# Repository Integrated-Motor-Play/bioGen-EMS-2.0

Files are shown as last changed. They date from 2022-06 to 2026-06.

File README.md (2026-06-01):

# bioGen-EMS-2.0

**bioGen-EMS 2.0** is an open-source, programmable four-channel Electrical Muscle Stimulation (EMS) toolkit for HCI research, rehabilitation experiments, interactive installations, and body-actuating games.

It builds on [bioGen-EMS](https://github.com/Integrated-Motor-Play/bioGen-EMS) and works with [Auto-Paizo](https://github.com/Integrated-Motor-Play/Auto-Paizo) using a shared single-character control protocol over USB serial and BLE.

## Table of contents

- [Features](#features)
- [Circuit](#circuit)
- [Repository layout](#repository-layout)
- [Quick start](#quick-start)
- [Documentation](#documentation)
- [Hardware requirements](#hardware-requirements)
- [Safety](#safety)
- [Contributing](#contributing)
- [License](#license)

## Features

- **Four-channel relay control** via demultiplexer select lines (D1–D4)
- **Auto-Paizo compatible** commands (`A/a` … `D/d`, `E/e`, `r`) on serial and BLE
- **EMG telemetry** over BLE (Grove EMG on A0)
- **Production firmware** for Seeed XIAO nRF52840
- **Python CLI** for bench testing without Unity
- **Open-source** hardware CAD, circuit, and firmware (MIT)

## Circuit

bioGen-EMS-2.0 Circuit

Schematic: [`Circuit Designs/bioGen-EMS-2.0.ckt`](Circuit%20Designs/bioGen-EMS-2.0.ckt) (open in Cirkit Studio)

## Repository layout

```
bioGen-EMS-2.0/
├── firmware/biogen_ems/    # Production sketch (Seeed XIAO nRF52840)
├── python/                 # Serial control CLI
├── examples/               # Example scripts
├── docs/                   # BOM, assembly, safety, protocol, enclosure
├── hardware/               # Hardware documentation index
├── CAD Files/              # Enclosure V2.0–V2.2 (use V2.2)
├── Circuit Designs/
└── Test Code/              # Legacy bring-up sketches (deprecated)
```

## Quick start

### 1. Clone and install Python dependencies

```bash
git clone https://github.com/Integrated-Motor-Play/bioGen-EMS-2.0.git
cd bioGen-EMS-2.0
pip install -r python/requirements.txt
```

### 2. Flash firmware

1. Install the [Seeed nRF52 board package](https://wiki.seeedstudio.com/XIAO_BLE/) in Arduino IDE.
2. Install the **ArduinoBLE** library from Library Manager.
3. Open [`firmware/biogen_ems/biogen_ems.ino`](firmware/biogen_ems/biogen_ems.ino).
4. Select **Seeed XIAO nRF52840** and upload.

See [firmware/README.md](firmware/README.md) for the smoke-test checklist.

### 3. Control over USB serial

```bash
# List available serial ports
python python/ems_control.py --list-ports

# Pulse channel 1 for 500 ms (auto-selects first port if --port omitted)
python python/ems_control.py --port /dev/cu.usbmodem101 --pulse 1 --duration 500

# Turn channel 2 on / off
python python/ems_control.py --port /dev/cu.usbmodem101 --channel 2 --on
python python/ems_control.py --port /dev/cu.usbmodem101 --channel 2 --off

# Reset all channels
python python/ems_control.py --port /dev/cu.usbmodem101 --reset
```

On Windows, use `COM3` (or your port) instead of `/dev/cu.usbmodem101`.

Example script: [`examples/basic_stim.py`](examples/basic_stim.py)

### 4. Build the hardware

1. [Bill of materials](docs/bom.md)
2. [Assembly guide](docs/assembly.md)
3. [Enclosure V2.2](docs/enclosure.md) — laser-cut acrylic + 3D-printed top/base

### 5. Use with Auto-Paizo

Pair over BLE and run calibration before participant sessions. See [docs/auto-paizo.md](docs/auto-paizo.md).

## Documentation

| Document | Description |
|---|---|
| [docs/bom.md](docs/bom.md) | Bill of materials |
| [docs/pinout.md](docs/pinout.md) | MCU pin mapping |
| [docs/protocol.md](docs/protocol.md) | Serial and BLE command reference |
| [docs/assembly.md](docs/assembly.md) | Build order and wiring |
| [docs/safety.md](docs/safety.md) | Safety and ethics guidelines |
| [docs/enclosure.md](docs/enclosure.md) | V2.2 enclosure manufacturing files |
| [docs/changelog-hardware.md](docs/changelog-hardware.md) | Enclosure revision history |
| [docs/auto-paizo.md](docs/auto-paizo.md) | Unity / Auto-Paizo integration |
| [hardware/README.md](hardware/README.md) | Hardware doc index |
| [CAD Files/README.md](CAD%20Files/README.md) | CAD file index |

## Hardware requirements

| Component | Notes |
|---|---|
| Seeed XIAO nRF52840 | Main controller |
| 4× Adafruit STEMMA Relay (4409) | Per-channel switching |
| 4-channel demux | Select lines on D1–D4 |
| Off-the-shelf EMS/TENS unit | Stimulation source (switched by relays) |
| Grove EMG Detector | Optional; muscle activity on A0 |
| Electrodes and cables | Per EMS unit manufacturer |

## Safety

EMS affects the human body. Read [docs/safety.md](docs/safety.md) before building or running studies. Use ethics approval, informed consent, conservative intensity, and never test on participants without proper calibration and supervision.

## Contributing

1. Fork the repository.
2. Create a branch: `git checkout -b feature/your-feature`
3. Commit your changes and open a pull request.

## License

MIT — see [LICENSE](LICENSE).

## Contact

hello@rakeshpatibanda.com

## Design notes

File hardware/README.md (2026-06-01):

# Hardware

Index for building the bioGen-EMS 2.0 device.

| Resource | Description |
|---|---|
| [docs/bom.md](../docs/bom.md) | Bill of materials |
| [docs/assembly.md](../docs/assembly.md) | Step-by-step assembly |
| [docs/pinout.md](../docs/pinout.md) | MCU pin mapping |
| [docs/enclosure.md](../docs/enclosure.md) | V2.2 enclosure files |
| [docs/safety.md](../docs/safety.md) | Safety guidelines |
| [Circuit Designs/bioGen-EMS-2.0.ckt](../Circuit%20Designs/bioGen-EMS-2.0.ckt) | Cirkit Studio schematic |
| [CAD Files/README.md](../CAD%20Files/README.md) | Enclosure file index |

Firmware: [firmware/README.md](../firmware/README.md)

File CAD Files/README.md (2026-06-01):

# CAD Files

## Current revision: V2.2

Use **`V2.2/`** for all new builds. See [docs/enclosure.md](../docs/enclosure.md).

### Files you need

| Process | Path |
|---|---|
| Laser cut (acrylic) | `V2.2/Acrylic.DXF`, `V2.2/Acrylic_front_back.DXF`, `V2.2/Acrylic_side.DXF`, `V2.2/Acrylic_right_left.DXF` |
| 3D print | `V2.2/Top.STL`, `V2.2/Base.STL` |

### Source CAD

SolidWorks assembly: `V2.2/BioGen_Box_Assembly.SLDASM`

## Legacy revisions

| Folder | Status |
|---|---|
| `V2.0/` | Legacy — early box + middle sections |
| `V2.1/` | Legacy — panelized drawings in `Drawings/` |
| `V2.2/` | **Current** |

Hardware changelog: [docs/changelog-hardware.md](../docs/changelog-hardware.md).

## Logo

`XGL_large X.png` — project branding asset.

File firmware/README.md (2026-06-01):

# Firmware

Production sketch: [`biogen_ems/biogen_ems.ino`](biogen_ems/biogen_ems.ino)

**Target board:** Seeed XIAO nRF52840 (Sense or non-Sense)

## Setup (Arduino IDE)

1. Install [Arduino IDE](https://www.arduino.cc/en/software) 2.x.
2. Add board package: **Seeed nRF52 Boards** via Board Manager (`https://files.seeedstudio.com/arduino/package_seeeduino_boards_index.json`).
3. Install library: **ArduinoBLE** (Library Manager).
4. Open `biogen_ems/biogen_ems.ino`.
5. Select **Seeed XIAO nRF52840** → upload.

## Configuration

Edit [`biogen_ems/config.h`](biogen_ems/config.h):

| Define | Default | Purpose |
|---|---|---|
| `PIN_SEL_A`–`D` | 1–4 | Demux select lines |
| `EMG_PIN` | A0 | Grove EMG analog input |
| `EMG_DEBUG_SERIAL` | 0 | Set `1` for CSV on Serial |
| `BLE_DEVICE_NAME` | BioGen-EMS | BLE advertised name |

## Smoke test checklist

Perform **without electrodes on a participant**.

### 1. Serial connection

1. Connect XIAO via USB; note the serial port (e.g. `/dev/cu.usbmodem*` on macOS).
2. Open Serial Monitor at **115200** baud.
3. Confirm boot message: `bioGen-EMS ready`.

### 2. Channel commands

Send one character per line (no intensity control):

| Send | Expected |
|---|---|
| `A` | Channel 1 ON (D1 HIGH, D2–D4 LOW) |
| `a` | Channel 1 OFF |
| `B` | Channel 2 ON |
| `r` | All channels OFF |

Verify with a multimeter or LED on demux lines if relays are not yet wired.

### 3. Python CLI

```bash
pip install -r python/requirements.txt
python python/ems_control.py --list-ports
python python/ems_control.py --port /dev/cu.usbmodemXXXX --pulse 1 --duration 500
python python/ems_control.py --port /dev/cu.usbmodemXXXX --reset
```

### 4. BLE (optional)

1. Scan for **BioGen-EMS** from a phone or nRF Connect.
2. Connect to service `19B10000-E8F2-537E-4F6C-D104768A1214`.
3. Write `0x42` (`B`) to characteristic `19B10001-...` → channel 2 ON.
4. Subscribe to EMG characteristic `19B10002-...` for int32 notifications.

### 5. Auto-Paizo

Flash this firmware, then follow [docs/auto-paizo.md](../docs/auto-paizo.md).

## Troubleshooting

| Issue | Check |
|---|---|
| BLE init failed | Board package and ArduinoBLE installed |
| No serial port | USB cable supports data; driver for J-Link/USB |
| Wrong channel | [docs/pinout.md](../docs/pinout.md) wiring vs `config.h` |
| EMG flatline | Grove EMG on A0; sensor powered |

## Legacy tests

Bring-up sketches in [`Test Code/`](../Test%20Code/) are deprecated; use this firmware instead.

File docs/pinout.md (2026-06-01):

# Pinout (Seeed XIAO nRF52840)

Production firmware: [`firmware/biogen_ems/`](../firmware/biogen_ems/).

## Demux select lines (channels 1–4)

| Signal | XIAO pin | Arduino define | Channel |
|---|---|---|---|
| SEL_A | D1 | `PIN_SEL_A` (1) | 1 |
| SEL_B | D2 | `PIN_SEL_B` (2) | 2 |
| SEL_C | D3 | `PIN_SEL_C` (3) | 3 |
| SEL_D | D4 | `PIN_SEL_D` (4) | 4 |

Each channel is selected by driving one select line HIGH and the others LOW. Reset (`r`) drives all select lines LOW.

Validated in [`Test Code/Test_Demux/Test_Demux.ino`](../Test%20Code/Test_Demux/Test_Demux.ino).

## EMG sensor

| Signal | Pin | Notes |
|---|-----|---|
| EMG analog | A0 | Production firmware (`EMG_PIN`) |
| EMG analog (legacy test) | A7 | Used in early `sketch_jul11a` demo only |

Connect the Grove EMG Detector to the analog input per Grove wiring (typically A0 on XIAO).

## Channel 0 (protocol `E` / `e`)

Auto-Paizo uses channel 0 for some game mappings. With a 4-line demux, channel 0 is implemented as **all select lines LOW** (no channel selected). `E` enables that idle state; `e` is equivalent to off.

## Built-in LED

`LED_BUILTIN` may toggle on channel activity for debugging (optional in firmware).

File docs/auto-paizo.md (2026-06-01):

# Auto-Paizo Integration

[bioGen-EMS 2.0](https://github.com/Integrated-Motor-Play/bioGen-EMS-2.0) is designed to work with [Auto-Paizo](https://github.com/Integrated-Motor-Play/Auto-Paizo), a Unity project for body-actuating play research.

## Requirements

- Seeed XIAO nRF52840 flashed with [`firmware/biogen_ems/biogen_ems.ino`](../firmware/biogen_ems/biogen_ems.ino)
- Windows or macOS with Bluetooth LE
- Auto-Paizo built from source (see Auto-Paizo README)

## Pairing

1. Power the controller; do **not** attach electrodes to a participant yet.
2. Put the XIAO in range; ensure firmware BLE is advertising (device name: `BioGen-EMS`).
3. Pair from the OS Bluetooth settings if required by your platform.
4. In Auto-Paizo, open the Bluetooth Connect scene and select the device via `BluetoothConnector`.

## Protocol

Auto-Paizo sends the same single-character commands documented in [protocol.md](protocol.md) to the BLE command characteristic.

EMG calibration uses the EMG characteristic notify stream (32-bit integer level).

## Calibration

Use in-app panels before participant play:

- `EMGCalibrationPanel`
- `EMGSensitivitySlider`

Hold the target muscle steady during baseline capture (see Grove EMG notes in firmware README).

## Safety

Follow [safety.md](safety.md) and your ethics protocol. Auto-Paizo documentation also lists conservative intensity and participant communication practices.

## Differences from bioGen-EMS 1.0

| | v1 | v2 |
|---|----|----|
| MCU | Adafruit Feather 32u4 Bluefruit LE | Seeed XIAO nRF52840 |
| Transport | Classic Bluetooth serial | BLE GATT + USB serial |
| Enclosure | Burger v1 STL | V2.2 box |
| Commands | Same `A/a`…`D/d`, `E/e`, `r` | Same |

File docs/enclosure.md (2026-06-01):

# Enclosure (V2.2 — current)

Use **`CAD Files/V2.2/`** for new builds. Older revisions (V2.0, V2.1) are legacy references only.

## V2.2 manufacturing files

### Laser cut (acrylic)

| File | Purpose |
|---|---|
| `Acrylic.DXF` | Main acrylic layout |
| `Acrylic_front_back.DXF` | Front/back panels |
| `Acrylic_side.DXF` | Side panels |
| `Acrylic_right_left.DXF` | Left/right panels |

### 3D print

| File | Purpose |
|---|---|
| `Top.STL` | Top shell |
| `Base.STL` | Bottom shell |

### SolidWorks source

Assembly and parts: `BioGen_Box_Assembly.SLDASM`, `Top.SLDPRT`, `Base.SLDPRT`, `Front-Back.SLDPRT`, `Left-Right.SLDPRT`, `Board.SLDPRT`, `Speaker.SLDPRT`.

### CNC / other

- `BioGen_Box_Assembly.gcode` — machine-specific; verify settings before running on your printer/CNC.

## Legacy revisions

| Version | Folder | Notes |
|---|---|---|
| V2.0 | `CAD Files/V2.0/` | Early burger-style stack; Seeed Xiao + STEMMA relay CAD |
| V2.1 | `CAD Files/V2.1/` | Panelized wood/acrylic drawings in `Drawings/` |
| V2.2 | `CAD Files/V2.2/` | **Current** — simplified acrylic, speaker cutout |

See [changelog-hardware.md](changelog-hardware.md) for differences.

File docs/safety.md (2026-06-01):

# Safety Guidelines

Electrical muscle stimulation (EMS) affects the human body. Use bioGen-EMS 2.0 only with appropriate training, ethics approval, and informed consent.

## Before every session

1. Obtain institutional ethics approval for human-participant research.
2. Explain the procedure and obtain informed consent.
3. Inspect electrodes and cables for damage.
4. Set the external EMS unit to the **lowest effective intensity**.
5. Run `r` (reset all channels) before attaching electrodes.
6. Calibrate using Auto-Paizo or serial EMG readout before gameplay.

## Electrode placement

- Follow manufacturer guidance for the EMS unit and electrodes.
- Do **not** place stimulation electrodes on the head, neck, chest, or broken skin.
- Avoid stimulation across the heart.
- Use only intended muscle groups for your study protocol.

## During use

- Participants must be able to stop stimulation immediately (researcher disconnects or sends `r`).
- Monitor for pain, burns, skin irritation, or unexpected muscle reactions.
- Keep sessions within approved duration and intensity limits.
- Never leave stimulation unattended.

## Contraindications (consult a qualified clinician)

Do not use EMS on participants with pacemakers, pregnancy, epilepsy, or other conditions where electrical stimulation is contraindicated unless explicitly cleared by medical oversight.

## Hardware

- Verify relay wiring before connecting the EMS unit.
- Use battery or isolated supplies as designed; avoid mains-connected DIY stim circuits.
- This kit **switches** an off-the-shelf EMS device; it does not replace certified medical device safety review.

## Research documentation

Record calibration values, channel mappings, and any adverse events per your ethics protocol.

Contact: hello@rakeshpatibanda.com for project questions.

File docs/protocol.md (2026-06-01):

# Control Protocol

bioGen-EMS 2.0 uses the same single-character command set as [Auto-Paizo](https://github.com/Integrated-Motor-Play/Auto-Paizo). Commands are one ASCII character; an optional trailing newline (`\n`) is accepted.

## Channel commands

| Command | Channel | Action |
|---|---|---|
| `A` | 1 | ON |
| `a` | 1 | OFF |
| `B` | 2 | ON |
| `b` | 2 | OFF |
| `C` | 3 | ON |
| `c` | 3 | OFF |
| `D` | 4 | ON |
| `d` | 4 | OFF |
| `E` | 0 | ON (all demux lines low / idle) |
| `e` | 0 | OFF |
| `r` | — | Reset all channels OFF |

There is **no intensity command** in this protocol. Stimulation strength is set on the external EMS unit; the controller only selects which channel is active.

## USB serial

- Baud rate: **115200**
- Send one character per command, e.g. `A` or `A\n`
- EMG debug CSV (when enabled): `raw,filtered,level` per line at 10 ms interval

## BLE GATT (Auto-Paizo compatible)

| Role | UUID |
|---|---|
| Service | `19B10000-E8F2-537E-4F6C-D104768A1214` |
| Command (write) | `19B10001-E8F2-537E-4F6C-D104768A1214` |
| EMG (notify) | `19B10002-E8F2-537E-4F6C-D104768A1214` |

- Write a single command byte to the command characteristic.
- EMG level is sent as a **32-bit signed integer** (little-endian) on notify.

## Example session (serial)

```text
A    # channel 1 ON
a    # channel 1 OFF
B    # channel 2 ON
r    # all OFF
```

## Python

See [`python/ems_control.py`](../python/ems_control.py) and [`python/biogen_protocol.py`](../python/biogen_protocol.py).

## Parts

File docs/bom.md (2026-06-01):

# Bill of Materials

Parts identified from the circuit design ([`Circuit Designs/bioGen-EMS-2.0.ckt`](../Circuit%20Designs/bioGen-EMS-2.0.ckt)) and CAD assembly (V2.2).

## Electronics

| Qty | Part | MPN / ID | Notes |
|-----|---|---|---|
| 1 | Seeed XIAO nRF52840 | — | Main MCU; USB serial + BLE |
| 1 | Seeed XIAO Expansion Board | — | Optional; matches V2.0 CAD |
| 4 | Adafruit STEMMA Relay | 4409 | Channel switching |
| 1 | SparkFun connector | PRT-13854 | Per circuit file |
| 1 | 4-channel demultiplexer | — | Select lines driven by D1–D4 |
| 1 | Grove EMG Detector | — | Muscle activity sensing on A0 |
| 1 | Off-the-shelf EMS/TENS unit | — | Stimulation source; switched by relays |
| — | Electrode pads & cables | — | For EMS output and EMG input |

## Enclosure (V2.2)

| Process | Files |
|---|---|
| Laser cut (acrylic) | `CAD Files/V2.2/Acrylic*.DXF` |
| 3D print | `CAD Files/V2.2/Top.STL`, `CAD Files/V2.2/Base.STL` |

See [enclosure.md](enclosure.md) for full file list.

## Tools

- Soldering iron, wire, breadboard or PCB
- Arduino IDE with Seeed nRF52 board package
- Laser cutter and/or 3D printer (for enclosure)

## Purchasing

- [Adafruit STEMMA Relay (4409)](https://www.adafruit.com/product/4409)
- [Seeed XIAO nRF52840](https://www.seeedstudio.com/XIAO-BLE-Sense-p-3721.html)
- [Grove EMG Detector](https://www.seeedstudio.com/Grove-EMG-Detector-p-1737.html)

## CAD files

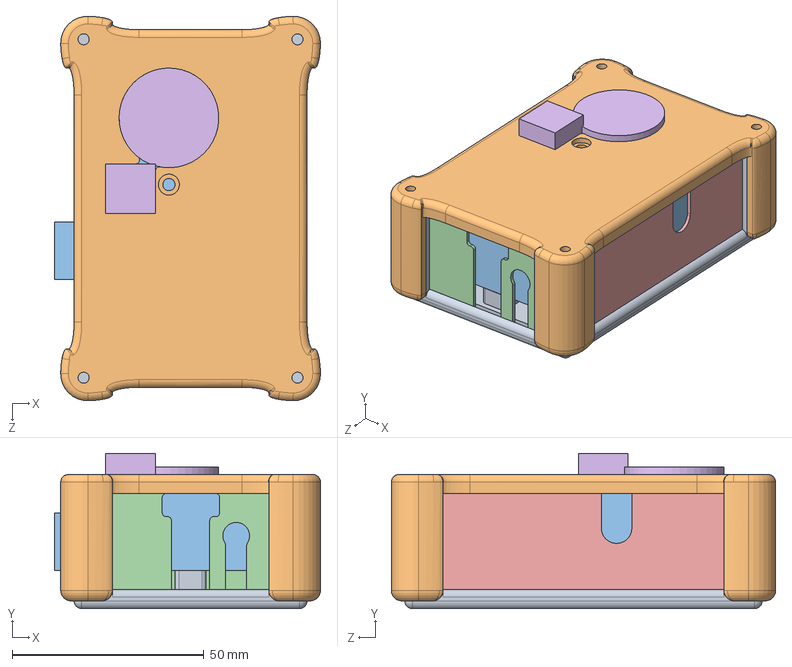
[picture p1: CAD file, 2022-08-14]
CAD Files/V2.2/BioGen_Box_Assembly.SLDASM
69.4 x 40.5 x 100.3 mm
Base
Top
Board
Front-Back x 2
Left-Right x 2

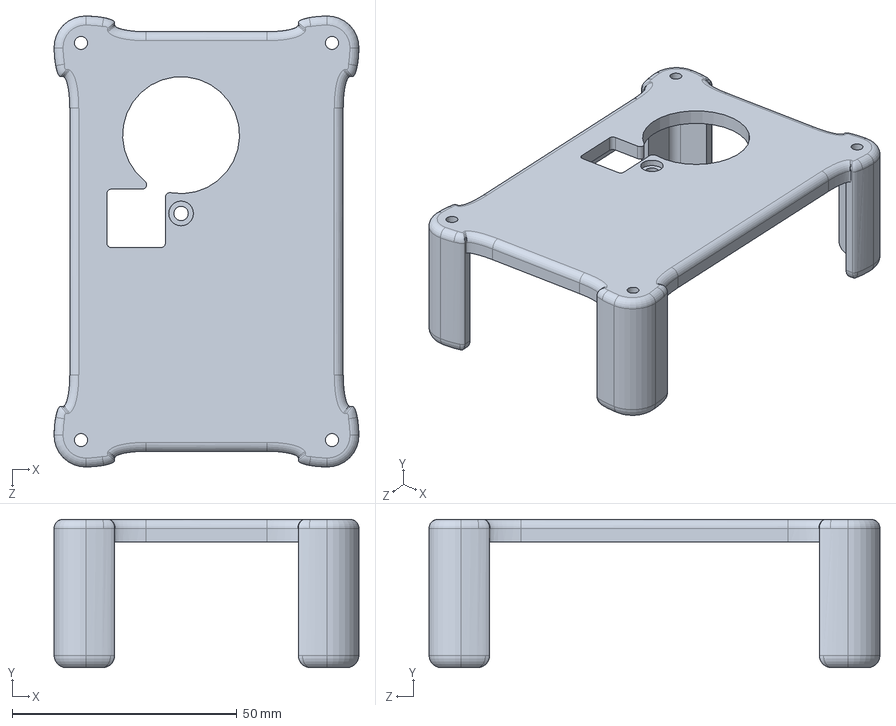
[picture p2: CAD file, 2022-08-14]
CAD Files/V2.2/Top.SLDPRT
67.8 x 33.0 x 100.3 mm

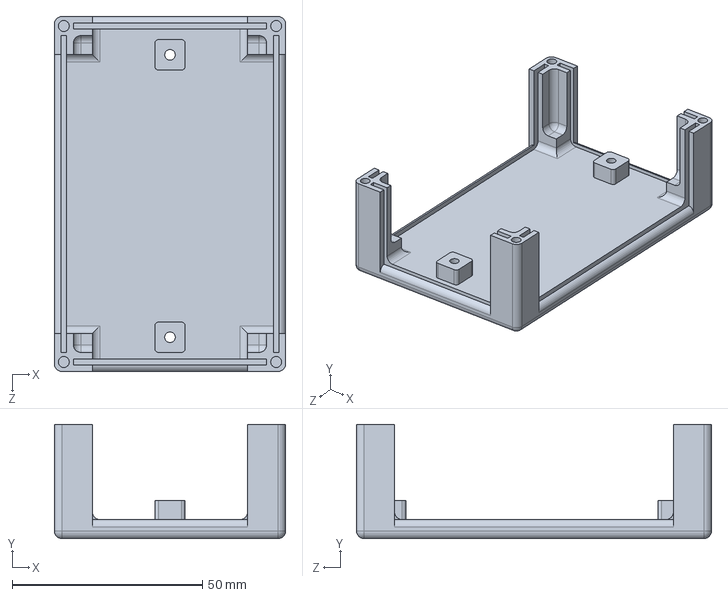
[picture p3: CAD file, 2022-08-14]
CAD Files/V2.2/Base.SLDPRT
60.8 x 30.0 x 93.3 mm

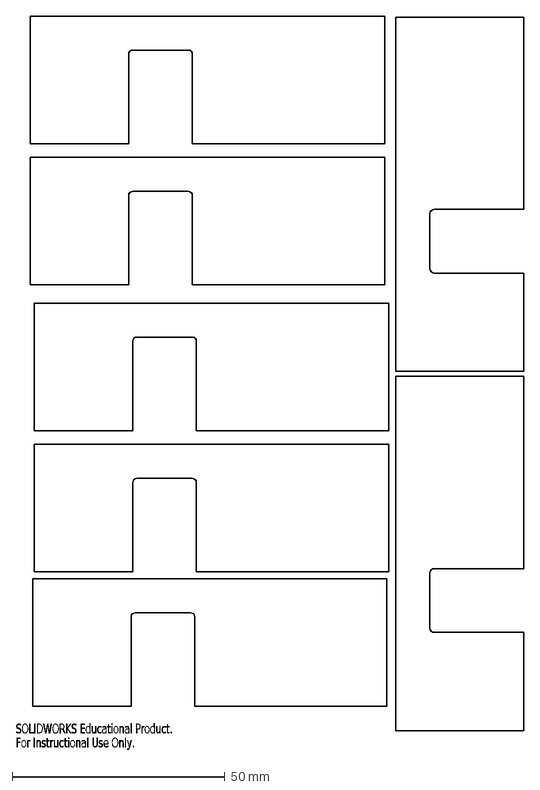
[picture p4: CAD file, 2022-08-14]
CAD Files/V2.2/Acrylic_side.DXF
SOLIDWORKS Educational Product.
For Instructional Use Only.

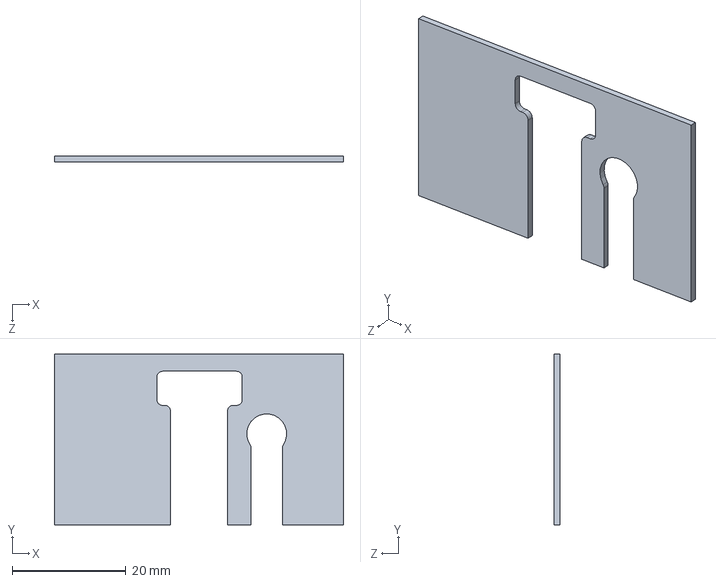
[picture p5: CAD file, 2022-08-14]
CAD Files/V2.2/Front-Back.SLDPRT
50.8 x 30.0 x 1.00 mm

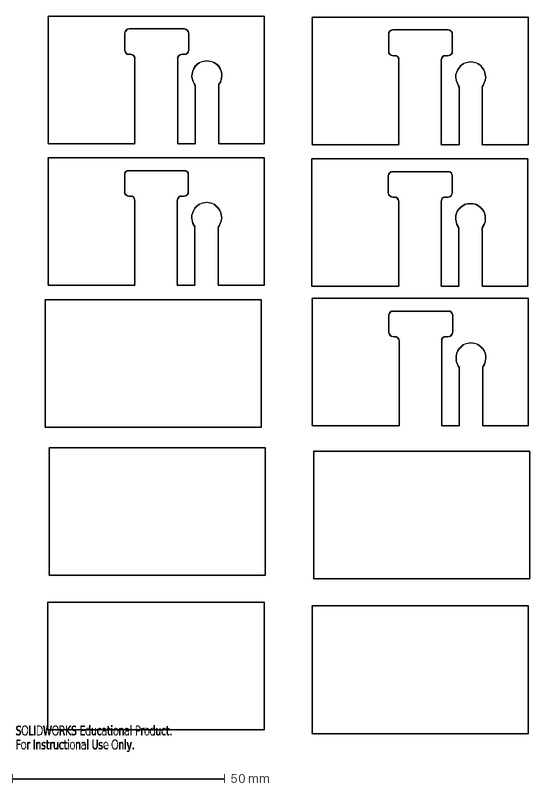
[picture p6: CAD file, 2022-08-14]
CAD Files/V2.2/Acrylic_front_back.DXF
SOLIDWORKS Educational Product.
For Instructional Use Only.

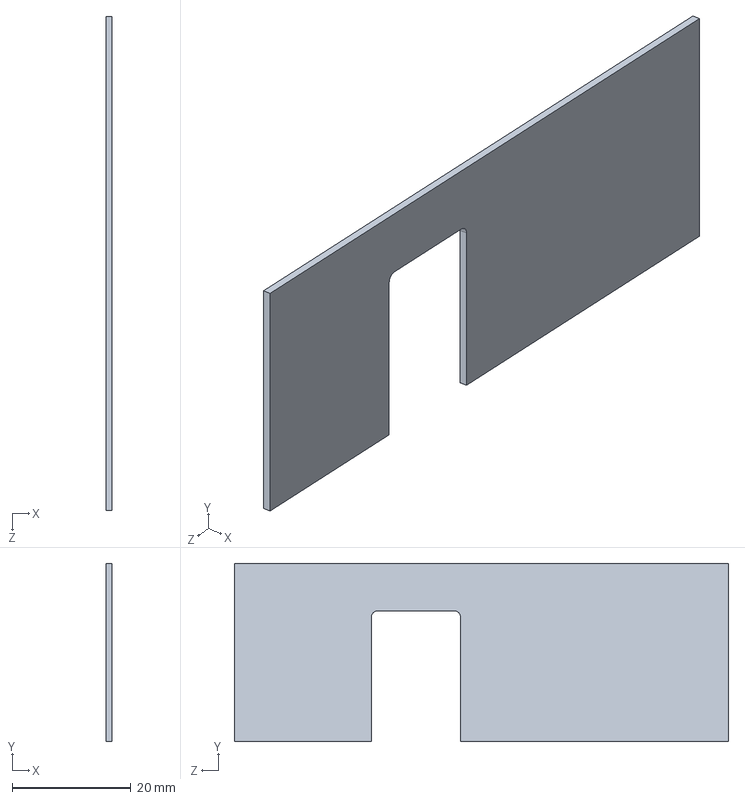
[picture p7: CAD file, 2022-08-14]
CAD Files/V2.2/Left-Right.SLDPRT
1.00 x 30.0 x 83.3 mm

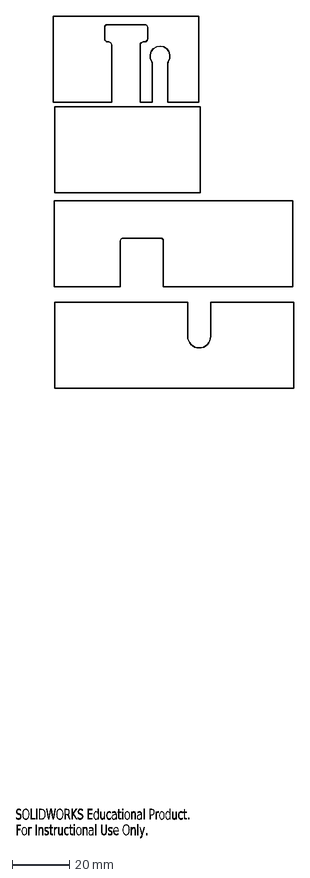
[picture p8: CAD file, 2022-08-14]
CAD Files/V2.2/Acrylic.DXF
SOLIDWORKS Educational Product.
For Instructional Use Only.

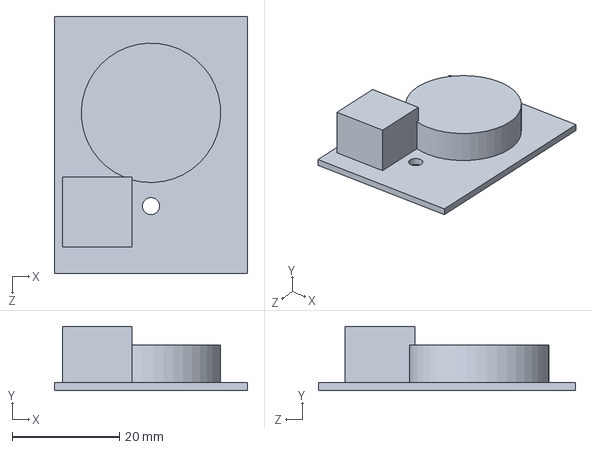
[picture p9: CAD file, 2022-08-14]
CAD Files/V2.2/Speaker.SLDPRT
36.0 x 12.0 x 48.0 mm

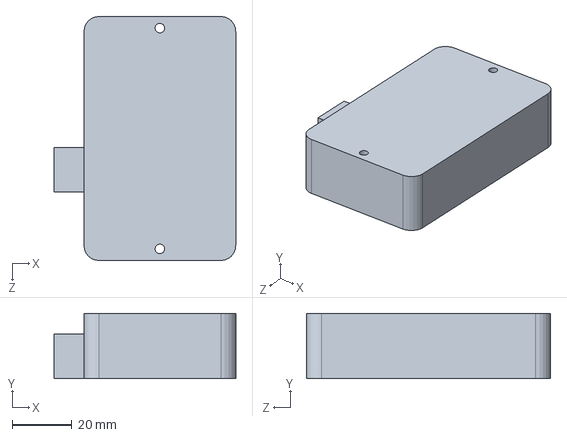
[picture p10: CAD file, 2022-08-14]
CAD Files/V2.2/Board.SLDPRT
61.0 x 22.0 x 82.0 mm

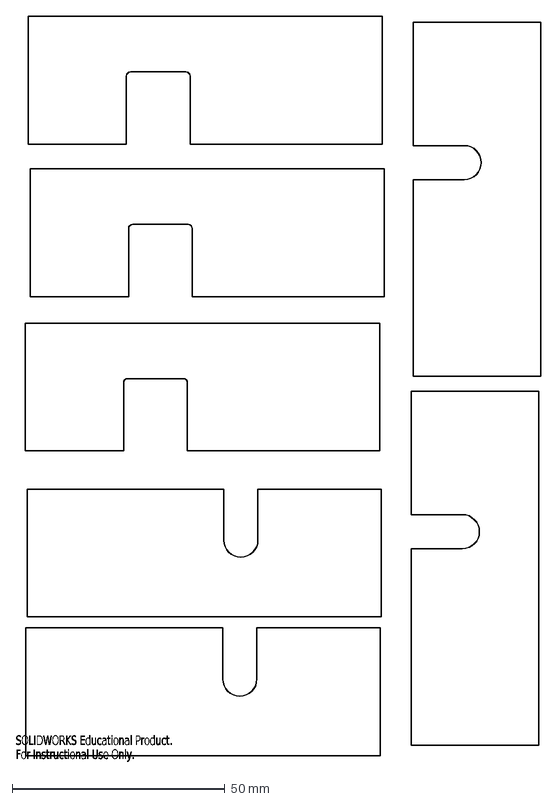
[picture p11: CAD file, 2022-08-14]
CAD Files/V2.2/Acrylic_right_left.DXF
SOLIDWORKS Educational Product.
For Instructional Use Only.

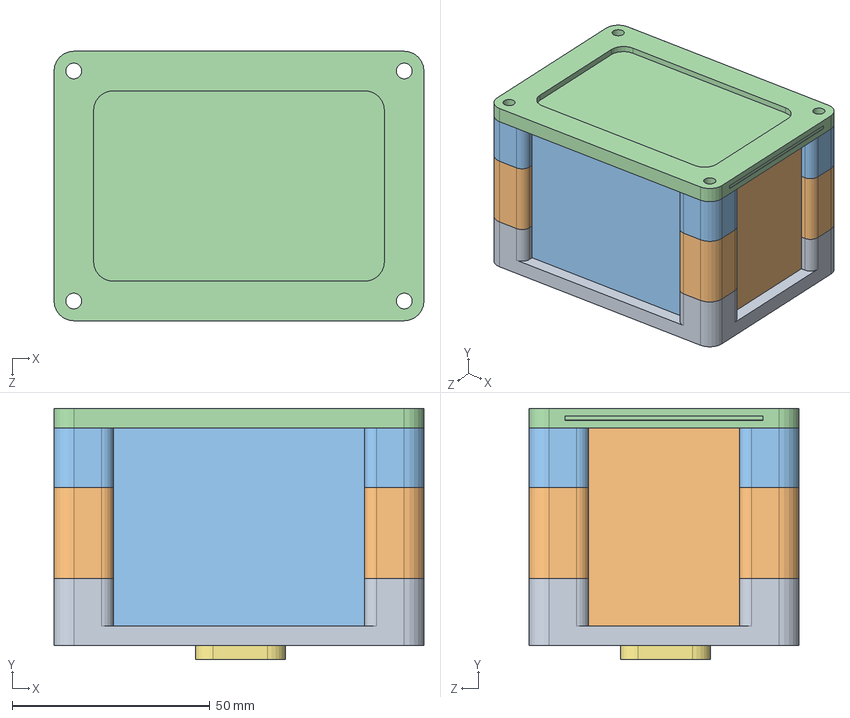
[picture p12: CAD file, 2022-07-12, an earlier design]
CAD Files/V2.0/BioGen_Box_Assembly_V2.0.SLDASM
93.6 x 63.5 x 68.2 mm
BioGen_Box_Bottom
BioGen_Box_Middle_Bottom x 2
BioGen_Box_Middle_Top x 2
BioGen_Box_Top
Seeed_Xiao_Expansion_Board
Stemma_Relay x 4
Arm_to_Box_Attach
500mAh_Battery
Grove_EMG_Detector
1mm_acrylic_sheet_small x 2
1mm_acrylic_sheet_big x 2
1mm_acrylic_sheet_top

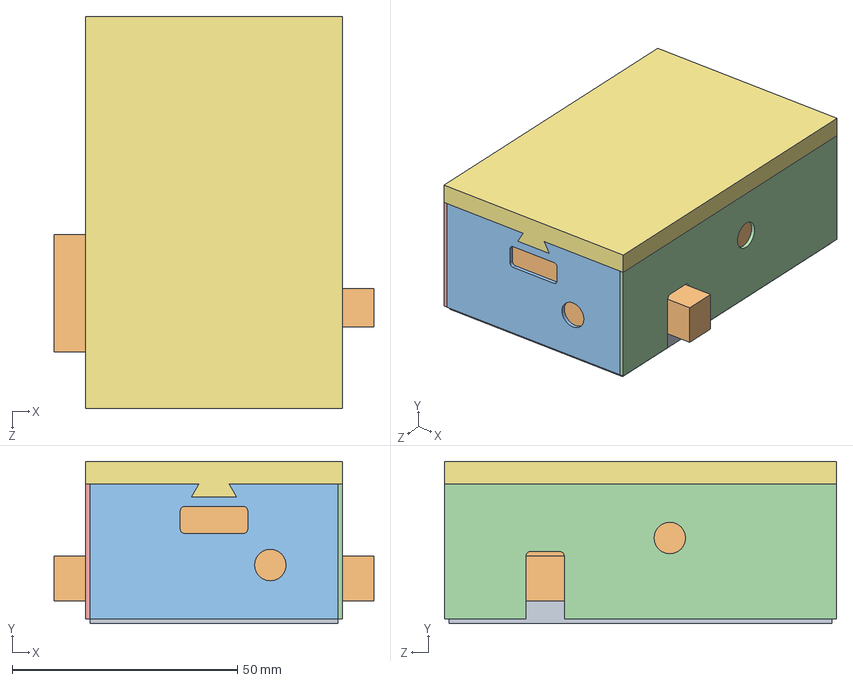
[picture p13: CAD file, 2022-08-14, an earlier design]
CAD Files/V2.1/BioGen_Box_Assembly.SLDASM
71.0 x 36.0 x 87.0 mm
Base
Board
Front
Right
Left
Back
Top

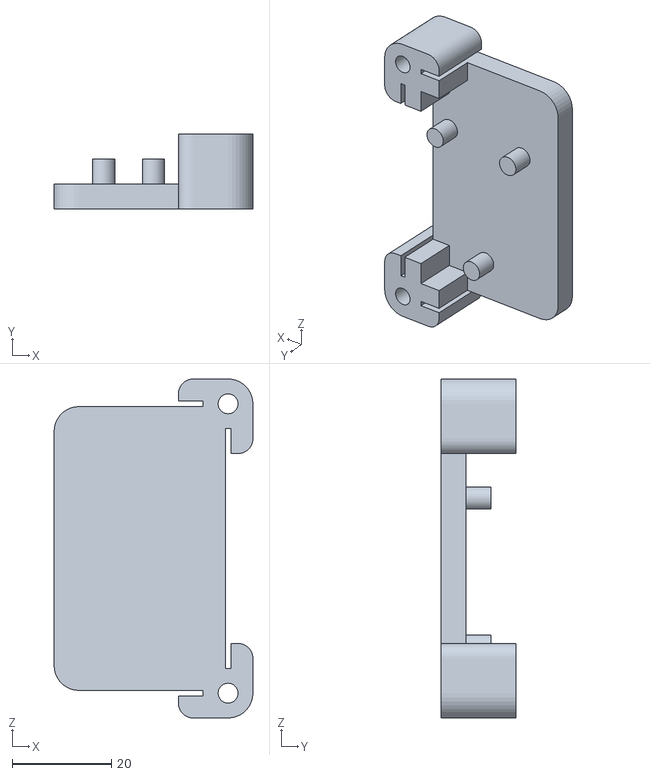
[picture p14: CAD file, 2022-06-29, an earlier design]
CAD Files/V2.0/STL/BioGen_Box_Middle_Top_Top.STL
40.0 x 15.0 x 68.2

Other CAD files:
CAD Files/V2.1/Board.SLDPRT
CAD Files/V2.1/Drawings/acrylic.DXF
CAD Files/V2.0/1mm_acrylic_sheet_big.SLDPRT
CAD Files/V2.0/STL/BioGen_Box_Middle_Bottom_Bottom.STL
CAD Files/V2.0/1mm_acrylic_sheet_small.SLDPRT
CAD Files/V2.0/1mm_acrylic_sheet_top.SLDPRT
CAD Files/V2.0/500mAh_Battery.SLDPRT
CAD Files/V2.0/Arm_to_Box_Attach.SLDPRT
CAD Files/V2.0/BioGen_Box_Bottom.SLDPRT
CAD Files/V2.0/BioGen_Box_Middle_Bottom.SLDPRT
CAD Files/V2.0/BioGen_Box_Middle_Top.SLDPRT
CAD Files/V2.0/BioGen_Box_Top.SLDPRT
CAD Files/V2.0/Grove_EMG_Detector.SLDPRT
CAD Files/V2.0/STL/BioGen_Box_Bottom.STL
CAD Files/V2.0/STL/BioGen_Box_Middle_Bottom_Top.STL
CAD Files/V2.0/STL/BioGen_Box_Middle_Top_Bottom.STL
CAD Files/V2.0/STL/BioGen_Box_Top.STL
CAD Files/V2.0/Seeed_Xiao_Expansion_Board.SLDPRT
CAD Files/V2.0/Stemma_Relay.SLDPRT
CAD Files/V2.1/Back.SLDPRT
CAD Files/V2.1/Base.SLDPRT
CAD Files/V2.1/Drawings/Back.DXF
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

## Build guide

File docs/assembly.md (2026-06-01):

# Assembly Guide

Build order for bioGen-EMS 2.0.

## 1. Review the circuit

1. Open [`Circuit Designs/bioGen-EMS-2.0.ckt`](../Circuit%20Designs/bioGen-EMS-2.0.ckt) in Cirkit Studio (or export the schematic image from the README).
2. Confirm parts against [bom.md](bom.md).

## 2. Wire the electronics

1. Mount the Seeed XIAO nRF52840 (and expansion board if used).
2. Connect demux select lines to **D1–D4** per [pinout.md](pinout.md).
3. Wire four STEMMA relays for channel switching to the EMS unit outputs.
4. Connect the Grove EMG detector to **A0**.
5. Double-check power, ground, and relay common paths before powering the EMS unit.

## 3. Flash firmware

1. Install the Seeed nRF52 board package in Arduino IDE.
2. Open [`firmware/biogen_ems/biogen_ems.ino`](../firmware/biogen_ems/biogen_ems.ino).
3. Select board **Seeed XIAO nRF52840** and upload.
4. Run serial smoke tests from [firmware/README.md](../firmware/README.md).

## 4. Build the enclosure

Follow [enclosure.md](enclosure.md) for V2.2 laser-cut and 3D-printed parts.

## 5. Pre-use checks

1. **Without electrodes on a participant**: send `A`, then `a`, then `r` over serial; verify only one channel selects at a time.
2. Set EMS unit intensity to minimum before first attached test.
3. Read [safety.md](safety.md) and complete ethics/calibration steps for research use.

## 6. Software integration

- **Python CLI**: [`python/ems_control.py`](../python/ems_control.py)
- **Auto-Paizo**: [auto-paizo.md](auto-paizo.md)

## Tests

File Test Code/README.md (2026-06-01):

# Test Code (legacy)

Bring-up sketches used during hardware development. **Use [`firmware/biogen_ems/`](../firmware/biogen_ems/) for production.**

| Sketch | Purpose |
|---|---|
| `Blink/` | Board LED sanity check |
| `Test_Demux/` | Cycle D1–D4 demux lines |
| `Test_EMG/` | Early EMG serial experiment (STL-heavy; may not compile on nRF52) |

The `Test_Demux/sketch_jul11a/` duplicate was removed; it referenced an undefined LED bar library.

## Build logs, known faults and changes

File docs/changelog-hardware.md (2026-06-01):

# Hardware Revision Changelog

## V2.2 (current)

- Simplified acrylic panel set (`Acrylic_*.DXF`)
- Added speaker component in CAD (`Speaker.SLDPRT`)
- STL exports for Top and Base
- Recommended for all new builds

## V2.1

- Panelized enclosure with separate Front, Back, Left, Right, Base, Top
- Laser drawings under `CAD Files/V2.1/Drawings/` (DXF + SolidWorks drawings)
- Wood and acrylic AI/DXF artwork for fab shops

## V2.0

- Initial bioGen-EMS 2.0 box assembly (`BioGen_Box_Assembly_V2.0.SLDASM`)
- Middle section split (top/bottom) STLs
- CAD references: Seeed Xiao expansion board, Grove EMG, STEMMA relay, 500 mAh battery

## Firmware / protocol

- V2.0 repo shipped test sketches only
- Production firmware (Seeed XIAO nRF52840) added with Auto-Paizo-compatible protocol

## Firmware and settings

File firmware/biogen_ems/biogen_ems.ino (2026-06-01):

/*
 * bioGen-EMS 2.0 — Seeed XIAO nRF52840
 * Auto-Paizo compatible EMS channel control + EMG telemetry
 */

#include <ArduinoBLE.h>
#include "config.h"

BLEService biogenService(BIOGEN_SERVICE_UUID);
BLEByteCharacteristic cmdCharacteristic(BIOGEN_CMD_CHAR_UUID, BLEWrite | BLERead);
BLEIntCharacteristic emgCharacteristic(BIOGEN_EMG_CHAR_UUID, BLENotify);

const int selPins[4] = {PIN_SEL_A, PIN_SEL_B, PIN_SEL_C, PIN_SEL_D};
int activeChannel = 0;  // 0 = none, 1-4 = demux channel

// EMG smoothing state
int emgMax = 300;
int emgMin = 100;
int emgLevel = 0;
int emgHistory[6];
int smoothHistory[6];
uint8_t historyLen = 0;
unsigned long lastEmgMs = 0;

int readEmgAveraged() {
  long sum = 0;
  for (int i = 0; i < 32; i++) {
    sum += analogRead(EMG_PIN);
  }
  int val = (int)(sum >> 5);
  if (val > emgMax) emgMax = val;
  if (val < emgMin) emgMin = val;
  return val;
}

bool isMonotonic(int* arr, int len) {
  if (len < 2) return true;
  bool inc = true, dec = true;
  for (int i = 1; i < len; i++) {
    if (arr[i] < arr[i - 1]) inc = false;
    if (arr[i] > arr[i - 1]) dec = false;
  }
  return inc || dec;
}

int smoothness(int* arr, int len) {
  if (len < 5) return 0;
  int hi = arr[0], lo = arr[0];
  for (int i = 1; i < len; i++) {
    if (arr[i] > hi) hi = arr[i];
    if (arr[i] < lo) lo = arr[i];
  }
  if (isMonotonic(arr, len)) return 0;
  return hi - lo;
}

int average(int* arr, int len) {
  if (len == 0) return 0;
  long sum = 0;
  for (int i = 0; i < len; i++) sum += arr[i];
  return (int)(sum / len);
}

void shiftPush(int* arr, int len, int value) {
  for (int i = 0; i < len - 1; i++) {
    arr[i] = arr[i + 1];
  }
  arr[len - 1] = value;
}

void applyChannel(int channel) {
  for (int i = 0; i < 4; i++) {
    digitalWrite(selPins[i], (channel == i + 1) ? HIGH : LOW);
  }
  activeChannel = channel;
}

void resetAllChannels() {
  applyChannel(0);
}

void handleCommand(char c) {
  switch (c) {
    case 'A': applyChannel(1); break;
    case 'a': if (activeChannel == 1) resetAllChannels(); break;
    case 'B': applyChannel(2); break;
    case 'b': if (activeChannel == 2) resetAllChannels(); break;
    case 'C': applyChannel(3); break;
    case 'c': if (activeChannel == 3) resetAllChannels(); break;
    case 'D': applyChannel(4); break;
    case 'd': if (activeChannel == 4) resetAllChannels(); break;
    case 'E':
    case 'e':
      resetAllChannels();
      break;
    case 'r':
    case 'R':
      resetAllChannels();
      break;
    default:
      break;
  }
}

void onCmdWritten(BLEDevice central, BLECharacteristic characteristic) {
  if (cmdCharacteristic.written()) {
    uint8_t value = cmdCharacteristic.value();
    handleCommand((char)value);
  }
}

void updateEmg() {
  unsigned long now = millis();
  if (now - lastEmgMs < EMG_SAMPLE_INTERVAL_MS) return;
  lastEmgMs = now;

  int raw = readEmgAveraged();
  if (historyLen < 6) {
    emgHistory[historyLen] = raw;
    smoothHistory[historyLen] = 0;
    historyLen++;
    return;
  }
  shiftPush(emgHistory, 6, raw);
  int s = smoothness(emgHistory, 5);
  shiftPush(smoothHistory, 6, s);
  int target = average(smoothHistory, 5) * 100;
  emgLevel += (int)((target - emgLevel) * 0.1f);

  emgCharacteristic.writeValue(emgLevel);

#if EMG_DEBUG_SERIAL
  Serial.print(raw);
  Serial.print(',');
  Serial.print(target);
  Serial.print(',');
  Serial.println(emgLevel);
#endif
}

void setup() {
  for (int i = 0; i < 4; i++) {
    pinMode(selPins[i], OUTPUT);
    digitalWrite(selPins[i], LOW);
  }
  pinMode(LED_BUILTIN, OUTPUT);

  Serial.begin(SERIAL_BAUD);
  while (!Serial && millis() < 3000) {
    ;  // wait for USB serial (timeout for battery use)
  }

  if (!BLE.begin()) {
    Serial.println("BLE init failed");
    while (1) {
      digitalWrite(LED_BUILTIN, !digitalRead(LED_BUILTIN));
      delay(200);
    }
  }

  BLE.setLocalName(BLE_DEVICE_NAME);
  BLE.setDeviceName(BLE_DEVICE_NAME);
  biogenService.addCharacteristic(cmdCharacteristic);
  biogenService.addCharacteristic(emgCharacteristic);
  BLE.addService(biogenService);
  cmdCharacteristic.setEventHandler(BLEWritten, onCmdWritten);
  emgCharacteristic.writeValue(0);

  BLE.advertise();
  Serial.println("bioGen-EMS ready");
}

void loop() {
  BLE.poll();

  while (Serial.available()) {
    char c = Serial.read();
    if (c == '\n' || c == '\r') continue;
    handleCommand(c);
  }

  updateEmg();
}

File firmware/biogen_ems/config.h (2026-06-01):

#ifndef BIOGEN_CONFIG_H
#define BIOGEN_CONFIG_H

// Demux select lines (channels 1-4)
#define PIN_SEL_A 1
#define PIN_SEL_B 2
#define PIN_SEL_C 3
#define PIN_SEL_D 4

#define EMG_PIN A0

#define SERIAL_BAUD 115200
#define EMG_SAMPLE_INTERVAL_MS 10

// Set to 1 to print EMG CSV on Serial for bench testing
#define EMG_DEBUG_SERIAL 0

// BLE device name
#define BLE_DEVICE_NAME "BioGen-EMS"

// Auto-Paizo compatible UUIDs
#define BIOGEN_SERVICE_UUID "19B10000-E8F2-537E-4F6C-D104768A1214"
#define BIOGEN_CMD_CHAR_UUID "19B10001-E8F2-537E-4F6C-D104768A1214"
#define BIOGEN_EMG_CHAR_UUID "19B10002-E8F2-537E-4F6C-D104768A1214"

#endif

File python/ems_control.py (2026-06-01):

#!/usr/bin/env python3
"""CLI for bioGen-EMS 2.0 over USB serial."""

from __future__ import annotations

import argparse
import sys
import time
from pathlib import Path

# Support running from repo root: python python/ems_control.py
sys.path.insert(0, str(Path(__file__).resolve().parent))

try:
    import serial
    import serial.tools.list_ports
except ImportError:
    print("Install dependencies: pip install -r python/requirements.txt", file=sys.stderr)
    sys.exit(1)

from biogen_protocol import (
    DEFAULT_BAUD,
    channel_off,
    channel_on,
    reset_all,
    send_command,
)


def list_ports() -> None:
    ports = serial.tools.list_ports.comports()
    if not ports:
        print("No serial ports found.")
        return
    for p in ports:
        print(f"  {p.device}\t{p.description}")


def open_port(port: str | None, baud: int) -> serial.Serial:
    if port is None:
        ports = list(serial.tools.list_ports.comports())
        if not ports:
            raise SystemExit("No serial port found. Use --list-ports or --port.")
        port = ports[0].device
        print(f"Using port {port}", file=sys.stderr)
    return serial.Serial(port, baud, timeout=1)


def monitor_emg(ser: serial.Serial) -> None:
    print("Monitoring EMG CSV (Ctrl+C to stop). Enable EMG_DEBUG_SERIAL in firmware.")
    try:
        while True:
            line = ser.readline().decode("utf-8", errors="replace").strip()
            if line:
                print(line)
    except KeyboardInterrupt:
        print("\nStopped.")


def main() -> None:
    parser = argparse.ArgumentParser(description="bioGen-EMS 2.0 serial control")
    parser.add_argument("--list-ports", action="store_true", help="List serial ports")
    parser.add_argument("--port", "-p", help="Serial port path")
    parser.add_argument("--baud", type=int, default=DEFAULT_BAUD)
    parser.add_argument("--channel", "-c", type=int, choices=[0, 1, 2, 3, 4])
    parser.add_argument("--on", action="store_true", help="Turn channel on")
    parser.add_argument("--off", action="store_true", help="Turn channel off")
    parser.add_argument("--pulse", action="store_true", help="Pulse channel on then off")
    parser.add_argument("--duration", type=int, default=500, help="Pulse duration ms")
    parser.add_argument("--reset", action="store_true", help="Reset all channels")
    parser.add_argument("--monitor-emg", action="store_true", help="Read EMG debug CSV")
    args = parser.parse_args()

    if args.list_ports:
        list_ports()
        return

    if args.monitor_emg:
        with open_port(args.port, args.baud) as ser:
            monitor_emg(ser)
        return

    if args.reset:
        with open_port(args.port, args.baud) as ser:
            send_command(ser, reset_all())
            print("Reset all channels.")
        return

    if args.channel is not None:
        with open_port(args.port, args.baud) as ser:
            if args.pulse:
                send_command(ser, channel_on(args.channel))
                time.sleep(args.duration / 1000.0)
                send_command(ser, channel_off(args.channel))
                print(f"Pulsed channel {args.channel} for {args.duration} ms.")
            elif args.on:
                send_command(ser, channel_on(args.channel))
                print(f"Channel {args.channel} ON.")
            elif args.off:
                send_command(ser, channel_off(args.channel))
                print(f"Channel {args.channel} OFF.")
            else:
                parser.error("Specify --on, --off, or --pulse with --channel")
        return

    parser.print_help()


if __name__ == "__main__":
    main()

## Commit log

2022-06-28 Create bioGen-EMS-2.0.ckt
    Initial Circuit Design
2022-06-29 Initial commit CAD files
    [500mAh_Battery.SLDPRT, Arm_to_Box_Attach.SLDPRT, BioGen_Box.SLDASM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]
2022-06-29 Completed V2.0 BioGen Box
    [1mm_acrylic_sheet_big.SLDPRT, 1mm_acrylic_sheet_small.SLDPRT, 1mm_acrylic_sheet_top.SLDPRT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]
2022-07-12 Add Box V2.1
    [Back.SLDPRT, Base.DXF, Base.SLDPRT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]
2022-07-12 Update Box V2.1
    [Base.SLDDRW, Board.SLDPRT, Left.SLDPRT]
2022-08-14 Add V2.2
    [Acrylic.DXF, Acrylic.SLDDRW, Acrylic_front_back.DXF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]
2026-06-01 Add firmware, Python CLI, and documentation for bioGen-EMS 2.0.
    Ship Seeed XIAO production firmware with Auto-Paizo protocol, expand docs
    (BOM, assembly, safety, protocol), add MIT license, and align README with
    the actual repository layout.
